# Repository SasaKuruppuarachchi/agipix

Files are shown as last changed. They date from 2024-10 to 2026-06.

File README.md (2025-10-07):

# [Agipix](https://sasakuruppuarachchi.github.io/agipix/) — Bridging Simulation and Reality for Aerial Robotics

banner

Agipix is an open hardware and software platform for agile indoor autonomy that runs the same ROS 2, containerized stack in both Isaac Sim and on the real robot. A small 438×372 mm footprint with a multi-modal sensor suite (3D LiDAR, RGB camera, IMU) and a Jetson Orin NX companion enables robust exploration and mapping with zero code changes from sim to real.

<p align="center">
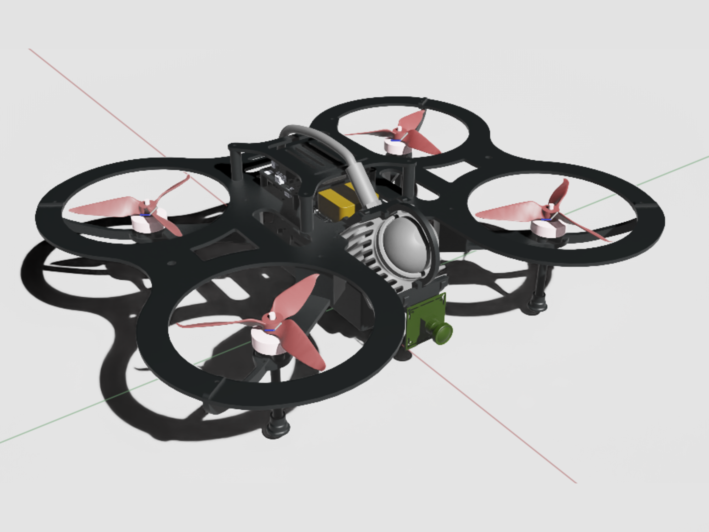
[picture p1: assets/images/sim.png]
Agipix simulation
	
	Agipix real prototype
</p>

For the accompanying paper-style write-up, see `todo` (IEEE conference format). It details hardware co-design, the LiDAR–inertial–visual stack, the Isaac Sim digital twin, and sim-to-real synchronization.

## Highlights

1) Sim-to-real deployability — Identical ROS 2 containers and configs run in Isaac Sim and on hardware; zero code changes between environments.

2) Open-source hardware and software — Full BOM, CAD, simulation assets, and the containerized ROS 2 stack are released in this repo: [bom/BOM.md](bom/BOM.md), [cad/](cad/), [model_exports/](model_exports/), [doc/](docs/), [LICENSE](LICENSE).

3) ROS 2–based modular autonomy stack — Perception, state estimation, mapping, planning, PX4 interface, and logging run as decoupled nodes/containers with DDS QoS tuning.

4) Small form factor for indoor navigation — Compact 438×372 mm envelope with guards; measured thrust-to-weight ratio (TWR) ≈ 2.98:1 for precise maneuvers in tight spaces.

5) Extensive sensor system incl. 3D LiDAR — 3D LiDAR, RGB camera, and IMU integrated into a LiDAR–inertial–visual stack for robust mapping and exploration.

6) Modular hardware with expandability — Layered decks and accessible power/data breakouts simplify sensor or compute upgrades without redesign.

## Repository layout

- `doc/` — Setup and usage guides
	- `sim/1_setup_sim.md` — Simulation setup
	- `real/1_hardware_assembly.md` — Hardware assembly
	- `real/2_flashing_hardware.Md` — Flashing and firmware
	- `real/3_software_setup.md` — Software setup on the robot
	- `autonomy/1_perception` - Perception side of the Agipix Autonomy
	- `autonomy/2_planning_control` - Planning and control side of the Agipix Autonomy
- `bom/` — Bill of Materials
	- `BOM.md` — Human-readable BOM
	- `bom.csv` — Source BOM (CSV)
- `cad/` — Mechanical CAD (designs and fabrication)
- `model_exports/` — Exported models (STL/USD) for sim and docs
- `calibration/` — Calibration assets (real and sim)
- `assets/` — Images, videos, and datasheets used in docs
- `todo` — IEEE-style paper source describing Agipix

## Quick start

### Simulation
- Follow the steps in [Simulation setup](docs/sim/1_setup_sim.md) to bring up Isaac Sim and the ROS 2 containers.

### Real hardware
- Start with [Hardware assembly](docs/real/1_hardware_assembly.md) for assembly.
- Then [Flashing and firmware](docs/real/2_flashing_hardware.Md).
- Finally [Software setup](docs/real/3_software_setup.md) to deploy the containerized stack.

## Bill of Materials (BOM)

- Browse the human-friendly BOM: [bom/BOM.md](bom/BOM.md)
- Source CSV for spreadsheets/scripts: [bom/bom.csv](bom/bom.csv)

## CAD and Simulation Assets

- Mechanical CAD and fabrication files live in `cad/`.
- Exported meshes and scene assets are in `model_exports/`.

## Paper and citation

- Main manuscript: [root.tex](root.tex) (IEEE conference format). If you use Agipix in academic work, please cite the paper once available. Until then, you may reference this repository.

## License

This project is released under the terms in [LICENSE](LICENSE).

## Acknowledgment

Agipix is supported by RAICAM, MSCA HORIZON EU.

## Contact Authors

- Sasanka Kuruppu Arachchige — sasa.kuruppuarachchi@gmail.com
- Joni Kämäräinen — joni.kamarainen@tuni.fi

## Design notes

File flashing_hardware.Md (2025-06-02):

# Compleate guide to flashing The Nvidia Jetson device to Jetpack 6.0

## Prerequisites 
1. Ubuntu 20.04 host machine x86

## Installation

4.1.2 Installing JetPack from NVIDIA® Embedded Download Center

 1. Create a new directory for installing the Jetpack. Referred to as <BSP_ROOT>
 in these instructions.

 2. Go to Jetpack Release Page https://developer.nvidia.com/embedded/jetson-linux-r363

 3. Download the "Driver Package (BSP)" and "Sample Root Filesystem" files for
 Orin modules (t234 platform).

 4. Put the "L4T Driver Package (BSP)" and "Sample Root Filesystem" in <BSP_ROOT>.
 Afterwards, you should have the following files in <BSP_ROOT>
• Jetson_Linux_R36.3.0_aarch64.tbz2
• Tegra_Linux_Sample-Root-Filesystem_R36.3.0_aarch64.tbz2

 5. Extract the "L4T Driver Package" tarball:

 cd <BSP_ROOT>
 sudo tar -jxf Jetson_Linux_R36.3.0_aarch64.tbz2

 6. You should now have a new directory called Linux_for_Tegra in your <BSP_ROOT> folder.
 Extract the "Sample Root Filesystem" into Linux_for_Tegra/rootfs.

 sudo tar -C Linux_for_Tegra/rootfs/ -xjf Tegra_Linux_Sample-RootFilesystem_R36.3.0_aarch64.tbz2

4.2 CTI BSP Installation

 1. Copy the CTI-L4T-ORIN-NX-NANO-36.3.0-V###.tgz package into
<BSP_ROOT>/Linux_for_Tegra.
If you are using Nvidia's SDK manager then "<BSP_ROOT>" will be:
 ~/nvidia/nvidia_sdk/<JetPack_Version>_Linux_JETSON_NX_ORIN_TARGETS/
 or
 ~/nvidia/nvidia_sdk/<JetPack_Version>_Linux_JETSON_NANO_ORIN_TARGETS/
 depending on your target module.

 Otherwise if manually installing from the NVIDIA® Embedded Download Center
 <BSP_ROOT> will be the folder created previously

 cp CTI-L4T-ORIN-NX-NANO-36.3.0-V###.tgz <BSP_ROOT>/Linux_for_Tegra

 2. Extract the BSP: tar -xzf CTI-L4T-ORIN-NX-NANO-36.3.0-V###.tgz
 cd <BSP_ROOT>/Linux_for_Tegra
 sudo tar -xzf CTI-L4T-ORIN-NX-NANO-36.3.0-V###.tgz

 3. Change into the CTI-L4T directory:
 cd <BSP_ROOT>/Linux_for_Tegra/CTI-L4T

 4. Run the install script (as root or sudo) to automatically install the BSP files
 to the correct locations:

 sudo ./install.sh
 #return to Linux_for_Tegra
 cd ..

 5. The CTI-L4T BSP is now installed on the host system and it should now be able
 to flash the Orin™ NX/Orin™ Nano module.

## Flasing
1. Connect an NVMe m.2 card to one of the m.2 slots on your Orin™ NX/Orin™ Nano carrier.

 2. Connect the Orin™ NX/Orin™ Nano and Carrier to the computer via USB, following the
 instructions in the appropriate manual.

 3. Put the system to be flashed into recovery mode, following the
 instructions in the appropriate manual

 4. There are two options for flashing Jetson modules:

 Using CTI's automated script:
 sudo ./cti-flash.sh

Follow the menu and select your desired configuration. Once selected,

 the device will start to flash.

 Using the Manual Method with cti-nvme-flash:

 Note do not add the ".conf" file extension to the <config> parameter:

 Manual Flash: sudo ./cti-nvme-flash.sh cti/<module>/<boardname>/<config>

 <module> is either orin-nx or orin-nano depending on your module.

 Examples:
 sudo ./cti-nvme-flash.sh cti/orin-nx/boson/base
 sudo ./cti-nvme-flash.sh cti/orin-nano/boson/base

 5. Once the flashing has completed, the Orin™ NX/Orin™ Nano will reboot 

## Connecting and first setup
1. conncet to the debug consol and follow the setup
https://jetsonhacks.com/2019/04/19/jetson-nano-serial-console/

2. skip network setup for now

3. connect to the network 
sudo nmcli dev wifi rescan

sudo nmcli d wifi connect [SSID] password [PASSWORD

4. ssh in
ssh [user]@[ip]

## Setting up Nomachine
https://kb.nomachine.com/AR02R01074

## change power mode
sudo nvpmodel -m <# of power mode>
https://forums.developer.nvidia.com/t/power-mode-in-terminal/287224

## isntalling docker and nvidia docker
https://docs.docker.com/engine/install/ubuntu/
https://docs.nvidia.com/datacenter/cloud-native/container-toolkit/latest/install-guide.html
https://git-lfs.com/

## compose and run docker

## build torchvision from source
We need to build torchvision from source in order to link against the right libraries as compiled with the NVIDIA-compiled build of pytorch
export FORCE_CUDA=1
git clone -b v0.17.2 https://github.com/pytorch/vision.git
cd vision
sudo -E python setup.py develop  # use install instead of develop if you don't care about development.

## Mount USB
https://linuxconfig.org/howto-mount-usb-drive-in-linux

## For livox lidar
- Set up the static ip of the Livox lidar Via LivoxViewer 2
- Set eth0 ip
```sudo ifconfig eth0 172.16.1.50 netmask 255.255.255.0 up```
(172.16.1.XX is the domain of the lidar)

## Referances
1. https://connecttech.com/product/hadron-carrier-for-nvidia-jetson-orin-nx/
2. https://connecttech.com/ftp/Drivers/L4T-Release-Notes/Jetson-Orin-NX-Orin-Nano/ORIN-NX-NANO-36.3.0.pdf
3. https://connecttech.com/resource-center/kdb373/
4. https://github.com/pytorch/vision/blob/main/CONTRIBUTING.md#development-installation

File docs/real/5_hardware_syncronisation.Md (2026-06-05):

---
title: Hardware Syncronisation
layout: doc
nav_title: HW Sync
---

# Hardware Syncronisation with ESP32 TimerSync Bridge

The default timesync method for Livox Lidars are PTP. But unfortunatly Jetson NX does not support PTP. The alternative in the official documentation is to use PPS syncronisation with GPS. As indoor focused robots do not have GPS, we designed the following solution to provide GPRMC and PPS signals to the Livox LiDAR and Px4 via a ESP32.

The ESP32 generates three hardware-synchronised outputs and disciplines its clock to the PX4 flight controller via MAVLink over UART.

The ESP32 firmware code can be found at [TimerSyncBridge](https://github.com/SasaKuruppuarachchi/esp32_timersync-open.git)

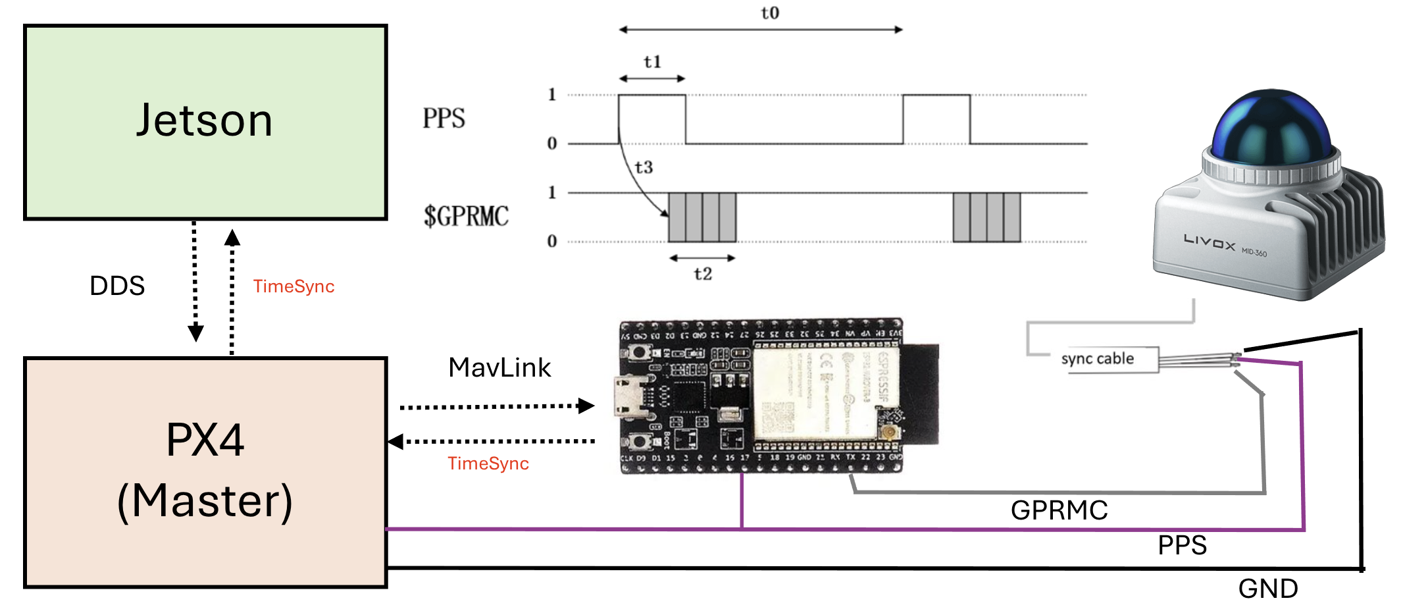
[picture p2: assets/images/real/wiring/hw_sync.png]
PPS sync wiring

---

## System Architecture

```
                          ┌─────────────────────────────────────┐
                          │   DFRobot FireBeetle 2 ESP32-S3     │
                          │                                     │
  PX4 Flight Controller   │  ┌──────────────────────────────┐   │
  (DDS time source)       │  │  Clock Discipline Layer      │   │
  GPS2  UART  ◄──────────►│  │  UNLOCKED → WARMING → LOCKED │   │
  GPIO 38/3               │  │  Source: SYSTEM_TIME MAVLink │   │
  57600 baud              │  └──────────┬───────────────────┘   │
                          │             │ UTC epoch              │
                          │  ┌──────────▼───────────────────┐   │
                          │  │  Output Generation           │   │
                          │  │  • 10 Hz PWM  GPIO 4 (LEDC)  │   │
                          │  │  • 1 Hz PPS   GPIO 5 (timer) │   │
                          │  │  • GPRMC      GPIO 12 UART1  │   │
                          │  └──┬──────────┬────────────────┘   │
                          └─────┼──────────┼──────────────────┘
                                │          │
               ┌────────────────┘          └──────────────────────────┐
               ▼                                                       ▼
  ┌────────────────────┐                          ┌────────────────────────────┐
  │  Hikrobot MVS      │                          │  Livox Mid-360             │
  │  Camera            │                          │  LiDAR                     │
  │  Line0 OPTO_IN     │                          │  Pin 8: PPS (Purple/white) │
  │  10 Hz trigger     │                          │  Pin 10: GPS/GPRMC         │
  │  → image timestamp │                          │    (Gray/white, UART 9600) │
  └────────────────────┘                          │  → UTC LiDAR stamps        │
                                                  └────────────────────────────┘
```

### Signal timing relationship

```
  1 Hz sync (GPIO 5)    ───┐           ┌───         ┌───
                           └───────────┘           └───
                           ▲ rising edge = UTC second boundary
                           │
  10 Hz trigger (GPIO 4)  ─┐─┐─┐─┐─┐  ←─ phase-reset here ─► ─┐─┐─┐─┐─┐
                            │ │ │ │ │                            │ │ │ │ │
                           100ms period, 50% duty

  GPRMC (GPIO 12 UART1)   ──[HHMMSS.00,A,...]──────────────────[HH:MM:SS+1,A,...]──
                           ▲ emitted on same rising edge
```

Every 1 Hz rising edge: LEDC timer reset (phase-aligns 10 Hz) → time increment → GPRMC emit.

---

## Hardware

| Component | Part |
|---|---|
| Timing board | DFRobot FireBeetle 2 ESP32-S3 |
| LiDAR | Livox Mid-360 |
| Camera | Hikrobot MVS (TriggerSource=LINE0) |
| Flight controller | PX4 (time sourced from companion via DDS, no GPS) |

---

## GPIO Pinout (as-built)

| Function | GPIO | Direction | Destination |
|---|---:|---|---|
| 10 Hz camera trigger | 4 | OUT | MVS camera Line0 OPTO_IN |
| 1 Hz PPS sync | 5 | OUT | Mid-360 M12 PPS interface (Pin 8, purple/white) (direct TTL) |
| GPRMC UART1 TX | 12 | OUT | Mid-360 M12 GPS input (Pin 10, Gray/white, UART 9600) |
| GPRMC UART1 RX | 13 | IN | Reserved, unused |
| MAVLink UART2 TX | 38 | OUT | PX4 GPS2 RX |
| MAVLink UART2 RX | 3 | IN | PX4 GPS2 TX |
| Status LED | 2 | OUT | On-board LED (0.5 Hz blink when LOCKED) |

---

## Px4 setup

Update Following parameters on PX4 to enable MAVLink time sync over UART2:
for refrance the project uses GPS2 port on PX4, so the parameters are:

```
MAV_1_CONFIG=GPS2
SER_GPS2_BAUD=57600
SER_GPS2_PROTO=1  # MAVLink v2
SER_GPS2_OPTIONS=0  # No flow control, no 9-bit, etc

UXRCE_DDS_SYCT=1
```

---

## Full Wiring Diagram

```
  FireBeetle 2 ESP32-S3
  ┌─────────────────────────────────────────────────────┐
  │                                                     │
  │  GPIO 4  ──────────────────────────────────────────►│  MVS Camera
  │  (10 Hz PWM 50% duty)                               │  Line0 OPTO_IN PIN 2
  │                                                     │
  │  GPIO 5  ──────────────────────────────────────────►│  Livox Mid-360
  │  (1 Hz PPS TTL 50% duty)                            │  M12 PPS interface (Pin 8, Purple/white)*
  │                                                     │  
  │  GPIO 12 (UART1 TX) ──┐────────────────────────────►│  M12 GPS input (Pin 10, Gray/white, UART 9600)*
  │  GPIO 13 (UART1 RX) ──┤                             │             
  │  (9600 baud GPRMC)    │                             │
  │                       ▼                             │
  │                  USB-Serial adapter                 │
  │                       │                             │
  │                       ▼                             │
  │                  Host /dev/ttyUSB0                  │
  │                  (to debug)                         │
  │                                                     │
  │  GPIO 38 (UART2 TX)  ──────────────────────────────►│  PX4 GPS2 RX
  │  GPIO  3 (UART2 RX)  ◄──────────────────────────────│  PX4 GPS2 TX
  │  (57600 baud MAVLink)                               │
  │  GND ───────────────────────────────────────────────│  PX4 GND
  │                                                     │
  │  USB-C (USB-CDC) ──────────────────────────────────►│  Host /dev/ttyACM0
  │  (115200 baud console)                              │  pio device monitor
  │                                                     │
  └─────────────────────────────────────────────────────┘
```
*(direct TTL for Mid-360 or when using the Livox converter 2.0, but RS485 is needed when using other LiDARs )
> **Mid-360 PPS note:** The Mid-360 accepts direct TTL on its M12 PPS interface. No TTL-to-RS485 converter is required.

> **UART TX/RX crossing:** GPIO 38 (TX) → PX4 GPS2 RX, GPIO 3 (RX) ← PX4 GPS2 TX. Cross the wires. Shared GND is mandatory.

---

## Clock Discipline Flow

```
  Power on
      │
      ▼
  UNLOCKED ──── no SYSTEM_TIME with valid epoch ────► UNLOCKED
      │
      │  SYSTEM_TIME.time_unix_usec > 1e15 µs (DDS converged)
      ▼
  WARMING ──── 3 consecutive SYSTEM_TIME samples ────► seed epoch, step-correct each
      │
      │  3 samples accumulated
      ▼
  LOCKED ──── ongoing SYSTEM_TIME updates ───────────► slew ±500 µs/update (D6)
      │                                                 GPRMC emits disciplined UTC
      │  DDS link lost
      ▼
  DEGRADED ── DDS re-converges ──────────────────────► WARMING (re-seeds)

  GPRMC output:  LOCKED → disciplined UTC sentences
                 all other states → suppressed (no output)

  1 Hz pulse and 10 Hz trigger: always running regardless of lock state
```

---

## Build and Flash

### Prerequisites
- PlatformIO CLI or VS Code PlatformIO extension
- `duracopter/MAVLink v2 C library@^2.0` (already in `platformio.ini`)

### Flash
```bash
pio run -t upload
```

### Monitor USB-CDC console
```bash
pio device monitor -b 115200
```

### Verify LiDAR time sync
The GPRMC signal goes directly to the LiDAR (M12 pin 10). Verify sync in `livox_ros_driver2` log — look for:
```
timestamp_type changed to 2
```
This confirms the LiDAR has accepted the GPRMC and switched to GPS/UART time sync mode.

---

## Expected Console Output

### Startup banner (Phase 4)
```
=== ESP32-S3 Phase 4 Timing Firmware ===
Board: DFRobot FireBeetle2 ESP32-S3
10Hz PWM trigger: GPIO 4 (LEDC low-speed timer0, 50% duty)
1Hz sync pulse:   GPIO 5 (esp_timer 500ms toggle, 50% duty)
GPRMC UART1:      TX GPIO 12, RX GPIO 13 @ 9600 baud
MAVLink UART2:    TX GPIO 38, RX GPIO 3 @ 57600 baud
DDS sync gate:    SYSTEM_TIME unix_us > 1e15 us (year >2001)
Clock discipline: UNLOCKED -> WARMING(3 samples) -> LOCKED
Max slew:         500 us/update  (D6 monotonic invariant)
GPRMC output:     disciplined UTC when LOCKED, suppressed otherwise
Invariant: on each 1Hz rising edge -> LEDC timer reset + monotonic time increment + GPRMC emit
```

### Before DDS lock (UNLOCKED/WARMING)
```
[1Hz] free=00:00:01 - GPRMC SUPPRESSED (clk=UNLOCKED), 10Hz phase reset
[MAV] HEARTBEAT sysid=1 compid=1 type=2 autopilot=12 base_mode=0x1D state=0
[MAV] SYSTEM_TIME unix_us=1780491609038000 boot_ms=2498713  dds=CONVERGED
[MAV] *** PX4 DDS timesync: CONVERGED — clock is valid ***
[CLK] state=WARMING sample=1/3  seed_unix_us=1780491609038000
[1Hz] free=00:00:02 - GPRMC SUPPRESSED (clk=WARMING), 10Hz phase reset
[CLK] state=WARMING sample=2/3  offset=1711 us
[CLK] state=WARMING sample=3/3  offset=-15801 us
[CLK] *** state=LOCKED — disciplined clock valid ***
```

### After LOCKED
```
[1Hz] disc=13:00:15 free=00:00:08 - GPRMC emitted (LOCKED), 10Hz phase reset
[CLK] state=LOCKED  disc_utc=13:00:16  offset=-1178 us  corr=-500 us  total_corr=-500 us  drift_trend=14623 us
[HB] uptime=10s  free=00:00:10  disc_utc=13:00:17  clk=LOCKED  px4_dds=CONVERGED
[MAV] TIMESYNC RTT=20639 us
```

### GPRMC output (GPIO 12 → Mid-360 pin 10, 9600 baud, after LOCKED)
```
$GPRMC,130015.00,A,2237.496474,N,11356.089515,E,0.0,225.5,230520,2.3,W,A*2E
$GPRMC,130016.00,A,2237.496474,N,11356.089515,E,0.0,225.5,230520,2.3,W,A*2D
$GPRMC,130017.00,A,2237.496474,N,11356.089515,E,0.0,225.5,230520,2.3,W,A*2C
```
Time field reflects real UTC from PX4. Checksum is valid NMEA XOR. Status field is `A` (active).

---

## livox_ros_driver2 Configuration

Time sync is configured in the Livox SDK JSON config used by `livox_ros_driver2`. The ESP32 acts as a GPS emulator — it provides both the 1 Hz PPS hardware edge (Mid-360 pin 8) and the GPRMC sentence (Mid-360 pin 10) directly. No host serial adapter is needed.

Reference: [Livox time sync via UART](https://livox-wiki-en.readthedocs.io/en/latest/tutorials/new_product/common/time_sync.html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)

The driver validates: `$GPRMC`/`$GNRMC` prefix, status field `A`, and checksum. It does **not** validate position or that the UTC value is current.

### Verification
After launching `livox_ros_driver2`, look for this log entry:
```
timestamp_type changed to 2
```
`timestamp_type 2` = GPS/UART sync active. If it reads `0` or `1`, the GPRMC signal is not reaching the LiDAR — check the GPIO 12 → pin 10 wire and GND continuity.

---

## Project Status

| Phase | Description | Status |
|---|---|---|
| 1 | ESP32 board bring-up — LEDC 10 Hz, 1 Hz PPS, free-running GPRMC | ✅ COMPLETE |
| 2 | MAVLink link bring-up — HEARTBEAT, SYSTEM_TIME, TIMESYNC via UART2 | ✅ COMPLETE |
| 3 | Clock discipline — DDS-gated UNLOCKED→WARMING→LOCKED state machine | ✅ COMPLETE |
| 4 | Disciplined GPRMC — UTC time from PX4 drives GPRMC output | ✅ COMPLETE — 32 min soak verified (offset ±13 ms, zero DEGRADED, ~16 µs/min drift) |
| 5 | Full integration — Mid-360 + MVS camera end-to-end | ✅ COMPLETE — PPS sync active, `timestamp_type changed to 2` confirmed |

---

## Phase 4 Soak Results (32-minute pre-Phase-5 run)

Continuous run with PX4 DDS active, no sensor hardware connected yet.

| Metric | Observed | Pass threshold |
|---|---|---|
| Clock state | LOCKED throughout | no DEGRADED transitions |
| Uptime | 1931 s (32 min) | — |
| GPRMC gaps | 0 | 0 |
| LOCKED offset range | ±13 ms | < ±50 ms (UART jitter) |
| Accumulated drift correction | −31 ms over 32 min (~16 µs/min) | stable tracking |
| MAVLink RTT | 20.6 ms (stable) | < 100 ms |
| px4_dds status | CONVERGED throughout | CONVERGED |

Representative log extract (uptime 1931 s):
```text
[HB] uptime=1931s  free=00:32:12  disc_utc=13:32:19  clk=LOCKED  px4_dds=CONVERGED
[CLK] state=LOCKED  disc_utc=13:32:20  offset=-12605 us  corr=-500 us  total_corr=-32166 us
[MAV] TIMESYNC RTT=20636 us
```

**Result: PASS.** Clock discipline is stable over the soak window. Proceeding to Phase 5.

## Phase 5 Integration Checklist

Connect the Mid-360 LiDAR and MVS camera to the ESP32 and run the full sensor stack.

**Step 1 — Wiring**
- GPIO 5 → Mid-360 M12 pin 8 (PPS, Purple/white, direct TTL 3.3V, no RS485)
- GPIO 12 UART1 TX → Mid-360 M12 pin 10 (GPS input, Gray/white, direct TTL 3.3V)
- GPIO 4 → MVS camera Line0 OPTO_IN
- Shared GND between ESP32 and Mid-360 M12 connector

**Step 2 — Host config**
- No serial adapter needed — GPRMC goes directly to LiDAR hardware
- Set camera: `TriggerMode=1`, `TriggerSource=LINE0`, `ExposureTime=5000`

**Step 3 — Launch**
- Flash ESP32 (`pio run -t upload`)
- Wait for `[CLK] *** state=LOCKED` in console before starting ROS nodes
- Launch `livox_ros_driver` and MVS camera driver

**Verification gate:**
- [ ] `livox_ros_driver2` log shows `timestamp_type changed to 2` on startup
- [ ] LiDAR point cloud timestamps are UTC-anchored (`sec` matches current UTC, not boot-relative)
- [ ] MVS camera triggers at 10 Hz confirmed in ROS topic
- [ ] 30-minute continuous run — no DEGRADED transitions in ESP32 console log
- [ ] Rosbag captured for evidence

---

## Troubleshooting

| Symptom | Likely cause | Fix |
|---|---|---|
| No `[MAV] HEARTBEAT` | UART2 wiring wrong or baud mismatch | Check GPIO 38→PX4 RX, GPIO 3←PX4 TX, shared GND; verify `SER_TELx_BAUD=57600` on PX4 |
| `clk=WARMING` never advances | PX4 DDS not converged | Check `uxrce_dds_client status` on PX4 NSH — need `timesync converged: true` |
| GPRMC suppressed indefinitely | Clock never reaches LOCKED | Usually DDS convergence issue; see above |
| `livox_ros_driver2` does not show `timestamp_type changed to 2` | GPRMC not reaching LiDAR | Check GPIO 12 → Mid-360 pin 10 wire and shared GND; confirm ESP32 is LOCKED before starting driver |
| 10 Hz or 1 Hz signal absent | GPIO conflict or wiring | Confirm scope on GPIO 4 and GPIO 5; check no strapping pin conflict |
| Large offset at LOCKED entry | Normal — WARMING step-corrects | Offset drops to <20 ms within a few SYSTEM_TIME updates after LOCKED |

---

## Repository Layout

```
esp32_timersync-open/
├── src/
│   └── main.cpp              # All firmware — Phase 1–4 complete
├── include/                  # Headers (currently empty)
├── platformio.ini            # Board: dfrobot_firebeetle2_esp32s3, lib: MAVLink v2
└── .copilot_instrcutions/    # Project knowledge base
    ├── SYSTEM_KNOWLEDGE.md   # Hardware facts, signal specs, verified GPIO table
    ├── PLAN.md               # Phase-gated implementation plan
    └── DECISIONS.md          # Resolved decisions and open questions
```

## Documentaion Reference

* [Wiki](https://github.com/Livox-SDK/Livox-SDK/wiki/livox-device-time-synchronization-manual)
* [PX4](https://discuss.px4.io/t/how-to-test-the-time-synchronization-between-radar-and-camera)
* [Livox ROS Driver](https://github.com/Livox-SDK/livox_ros_driver2)
* [LIV_handhold](https://github.com/xuankuzcr/LIV_handhold)

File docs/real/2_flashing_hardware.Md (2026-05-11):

---
title: Flashing Jetson & Carrier
layout: doc
nav_title: Flashing Hardware
---

# Flashing the NVIDIA Jetson (JetPack 6.x)

Refer to the [Datasheets](../../assets/datasheets/CTIM-00088.pdf) and install the Jetson Orin NX module, wiring and power to the Hadron carrier. 
Refer the [Official Page](https://connecttech.com/product/hadron-carrier-for-nvidia-jetson-orin-nx/) For the download of the latest official BSP (Board Support Package) and release notes which contains the firmware install instructions.

> Note: These steps target Jetson Orin NX/Nano on Connect Tech carriers (Hadron, etc.), Jetson Linux R36.3. Adjust versions as needed. 
**Tested for CT Hadron NGX027 with the Jetpack 6.2.1 - L4T r36.4.4 (BSP Version: ORIN-NX-NANO-36.4.4 V002)**

Prerequisities:
- x86/x64 based host machine running Ubuntu 20.04 or 22.04
- JetPack 6.2.1 / L4T 36.4.4 installed (Intstructions follows)
- Orin™ NX or Orin™ NX module
- Connect Tech Orin™ NX/Orin™ NX Carrier
- USB A - USB A Cable for flashing

## Install Wifi and SSD

Install the [wifi](https://www.intel.com/content/www/us/en/products/sku/230078/intel-wifi-7-be200/specifications.html) and [ssd](https://www.verkkokauppa.com/fi/product/906691/WD-Black-SN770M-1-Tt-M-2-NVMe-SSD-kovalevy) cards to the PCI mini E and M slots respectively.

## Powering up the carrier
The 6S Lipo can be used to power up the board directly. Install a 60V capacitor between the terminals of the main power.
Alternatively a AC DC adapter with min 40 W (10-60V) can be used.
 Get the board ready to be powered up for he flashing of firmware.

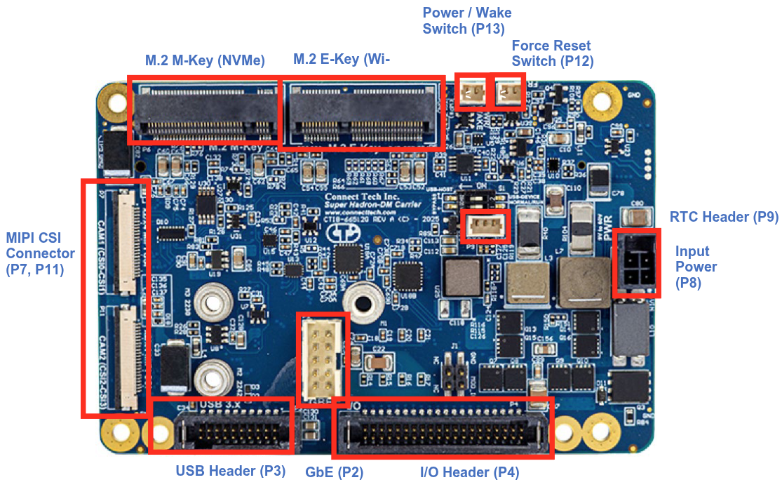
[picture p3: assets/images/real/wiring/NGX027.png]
Hadron Carrier


## What you’ll do
- Prepare a host machine and download JetPack BSP + sample rootfs
- Install the CTI BSP on the host
- Put the Jetson in recovery mode and flash (auto or manual)
- Perform first boot steps and basic post-setup

---

## 1) Get JetPack (Driver Package + RootFS)

1) Create a working directory, referred to as BSP_ROOT below.

2) Open the Jetson Linux R36.4.4 downloads and notes:
   - Driver page: https://developer.nvidia.com/embedded/jetson-linux-r3644

3) Download both for Orin (LT4):
   - Driver Package (BSP): Jetson_Linux_R36.4.4_aarch64.tbz2
   - Sample Root Filesystem: Tegra_Linux_Sample-Root-Filesystem_R36.4.4_aarch64.tbz2

4) Place both files under BSP_ROOT, then extract them:

```bash
cd <BSP_ROOT>
sudo tar -jxf Jetson_Linux_R36.4.4_aarch64.tbz2
sudo tar -C Linux_for_Tegra/rootfs/ -xjf Tegra_Linux_Sample-Root-Filesystem_R36.4.4_aarch64.tbz2
```

After extraction, you should have `<BSP_ROOT>/Linux_for_Tegra` populated.

---

## 2) Install the CTI BSP

If you used NVIDIA SDK Manager, BSP_ROOT is typically:
- `~/nvidia/nvidia_sdk/<JetPack_Version>_Linux_JETSON_NX_ORIN_TARGETS/`
- or `~/nvidia/nvidia_sdk/<JetPack_Version>_Linux_JETSON_NANO_ORIN_TARGETS/`

If you manually downloaded from the Embedded Download Center, use the folder you created as BSP_ROOT.

Download the CTI BSP from [CTI BSP Downloads](https://connecttech.com/product/super-hadron-dm-carrier-for-nvidia-jetson-orin-nx/).

For the firmware with real time kernel RT_PREEMPT download the `JetPack 6.2.1 – L4T r36.4.4 (RealTime OS)` package instead of the base package.

1) Copy the CTI package to Linux_for_Tegra:

```bash
cp CTI-L4T-ORIN-NX-NANO-RT-36.4.4-V005.tgz BSP_ROOT/Linux_for_Tegra
```

2) Extract it and run the installer:

```bash
cd <BSP_ROOT>/Linux_for_Tegra
sudo tar -xzf CTI-L4T-ORIN-NX-NANO-RT-36.4.4-V005.tgz
cd CTI-L4T
sudo ./install.sh
cd .. # back to Linux_for_Tegra
```

> The CTI-L4T BSP is now installed on the host, and you can flash Orin NX/Nano.

---

## 3) Put the device in Recovery Mode

1) Connect the carrier to your host via USB per the carrier manual.
2) Ensure an NVMe M.2 SSD is installed.
3) Follow the carrier instructions to enter recovery (button/strap sequence). 
> For NGX027 to put the Jetson module into Force Recovery mode, install a jumper and then power on the platform. After 10 seconds remove the jumper shunt and the device will now be in Force Recovery mode.

Tip: You can verify via `lsusb` for an NVIDIA device in recovery.
```shell
Bus 001 Device 024: ID 0955:7323 NVIDIA Corp. APX
```

---

## 4) Flashing options

You can use either the CTI automated script or the manual NVMe flash script.

### Option A: Automated (menu-driven)

```bash
cd <BSP_ROOT>/Linux_for_Tegra
sudo ./cti-flash.sh
```
Follow the menu to select your module and board configuration. Flashing will begin.

> `Vision Components IMX296` [camera option](https://www.mouser.fi/ProductDetail/Vision-Components/MIPI-IMX296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) for Orin NX is recommended for direct connection to the board.
[This](https://connecttech.com/supported-cameras/) Lists all the commpatible cameras.
[This](https://wdl.ai/connect-tech-allied-vision-mipi-csi-2) shows how to connect Allied vision cameras using adapter.

### Option B: Manual NVMe flash

Do not include the `.conf` extension in `<config>`.

```bash
cd <BSP_ROOT>/Linux_for_Tegra
sudo ./cti-nvme-flash.sh cti/<module>/<boardname>/<config>
# <module> is one of: orin-nx | orin-nano
```
Examples:
```bash
./cti-nvme-flash.sh cti/orin-nx/boson/base
./cti-nvme-flash.sh cti/orin-nano/boson/base
SUPER_MODE=1 ./cti-nvme-flash.sh cti/orin-nx/hadron/base
```

When flashing completes, the device will reboot.
```bash
Flash is successful
Reboot device
Cleaning up...
Log is saved to
```
---

### 5.1) Troubleshoot Flashing
#### ISSUE1 : A USB timeout error may occur during flashing. The following error indicates that your flash host’s USB port is not enabled:

```bash
[ 0.1172 ] Sending bct_br
[ 0.1603 ] ERROR: might be timeout in USB write.
Error: Return value
```
##### 1. First try changing the USB port:

- Move to a different USB port, if available.

- **Remove any USB-C docks if connected**

- Power cycle the board and retry flashing.

##### 2. If that doesn’t work, try disabling autosuspend:

To disable autosuspend on your host’s USB ports, run the following command.
```bash
sudo bash -c 'echo -1 > /sys/module/usbcore/parameters/autosuspend'
```
Power cycle the board and retry flashing.

#### ISSUE2 : Cnnot mount the NFS server

```bash
12:52:45.297 - Error: Flash failure. 
12:52:45.300 - Error: Either the device cannot mount the NFS server on the host or a flash command has failed. Check your network setting (VPN, firewall,...) to make sure the device can mount NFS server. Debug log saved to /tmp/tmp.2HZma7rFSi. You can access the target's terminal through "sshpass -p root ssh root@fc00:1:1:0::2"
```

##### 1. Disable VPN completely

CTI initrd flashing fails 100% if a VPN is on.

##### 2. Restart NFS and RPC services
```bash
sudo systemctl stop rpcbind rpcbind.socket nfs-kernel-server
sudo systemctl start rpcbind rpcbind.socket nfs-kernel-server
```

Check status:

```bash
systemctl status nfs-kernel-server
```
##### 3. Ensure firewall isn't blocking NFS (especially IPv6)

Temporarily disable ufw (if running):

```bash
sudo ufw disable
```
## 5) First boot and basic setup

### Connect via serial console (recommended)
- Connect to the **Serial debug port** of the Carrier using a TTL to USB adapter. (ex: FTDI)
- Guide: https://jetsonhacks.com/2019/04/19/jetson-nano-serial-console/ 
```bash
sudo minicom -D /dev/ttyUSB0 -b 115200
```
- Complete the initial setup prompts. You can skip network here and do it below.
```bash
System Configuration
           ┌────┤ License For Customer Use of NVIDIA Software ├─────┐
           │                                                        │
           │ Welcome to Jetson Initial Configuration                │
           │                                                        │
           │                         <Ok>                           │
           │                                                        │
           └────────────────────────────────────────────────────────┘
```

### Join Wi‑Fi via nmcli
```bash
sudo nmcli dev wifi rescan
sudo nmcli dev wifi connect <SSID> password <PASSWORD>
```

### SSH in
```bash
ssh <user>@<device-ip>
```

---

## 6) Useful post-setup

### Setup Git
```bash
git config --global user.name "John Doe"
git config --global user.email johndoe@example.com
```

### Increase Swap 
You may need to increase swap depending on he RAM of your Jetson module
Follow [This Guide](https://www.forecr.io/blogs/programming/how-to-increase-swap-space-on-jetson-modules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) to upgrade swap memeory.

```bash
free -h # Check current memory usage
df -h # Check current disk usage

# start from here to increase swap size to 16G
sudo fallocate -l 16G /swapfile # Allocate 16G of space for swap file
ls -lh /swapfile # Verify the swap file is created
sudo chmod 600 /swapfile # Set the correct permissions for the swap file
sudo mkswap /swapfile 
sudo swapon /swapfile
free -h # Check current memory usage   

# to make the change persistent across reboots, add the swap file to /etc/fstab:
sudo cp /etc/fstab /etc/fstab.bak
echo '/swapfile none swap sw 0 0' | sudo tee -a /etc/fstab
```

### Install Jetpack extras and Jtop
```bash
sudo apt install nvidia-jetpack

# Setup jtop
sudo apt update && sudo apt upgrade -y
sudo apt install python3-pip -y && sudo apt install curl -y
sudo pip3 install -U jetson-stats
mkdir hacks && cd hacks
git clone https://github.com/jetsonhacks/jetson-jtop-patch.git
cd jetson-jtop-patch
chmod +x apply_jtop_fix.sh
./apply_jtop_fix.sh
```
Once pip installs the jetson-stats package, you will need to logout/login or reboot the Jetson.

After rebooting, to run jtop open a Terminal and execute: `jtop`

### NoMachine (remote desktop)
To setup remote desktop to the headless system for debugging follow [this guide](https://kb.nomachine.com/AR02R01074)

```bash
wget https://web9001.nomachine.com/download/9.4/Arm/nomachine_9.4.14_1_arm64.deb
sudo dpkg -i nomachine_9.4.14_1_arm64.deb 
sudo systemctl disable gdm3 --now
sudo /usr/NX/bin/nxserver --restart
```

### Change power mode
```bash
sudo nvpmodel -m <mode-number>
```
- Reference: https://forums.developer.nvidia.com/t/power-mode-in-terminal/287224

### Install VSCode
```bash
cd hacks
git clone https://github.com/JetsonHacksNano/installVSCode.git
cd installVSCode
./installVSCodeWithPython.sh
```

### Cuda and cudnn
If cuda packages are not installed. ```ls /usr/local | grep cuda``` returns nothing
```bash
sudo apt install cuda-toolkit-12-6
```

if cudnn not installed. ```dpkg -l | grep cudnn``` returns nothing, [Get Cudnn](https://developer.nvidia.com/cudnn-downloads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)
```bash
wget https://developer.download.nvidia.com/compute/cudnn/9.16.0/local_installers/cudnn-local-tegra-repo-ubuntu2204-9.16.0_1.0-1_arm64.deb
sudo dpkg -i cudnn-local-tegra-repo-ubuntu2204-9.16.0_1.0-1_arm64.deb
sudo cp /var/cudnn-local-tegra-repo-ubuntu2204-9.16.0/cudnn-*-keyring.gpg /usr/share/keyrings/
sudo apt-get update
sudo apt-get -y install cudnn9-cuda-12
```

### Setup ```.bashrc```

Add following lines to your ```.bashrc``` to link important cuda libraries
```bash
export CUDA=12.6
export PATH=/usr/local/cuda-$CUDA/bin${PATH:+:${PATH}}
export CUDA_PATH=/usr/local/cuda-$CUDA
export CUDA_HOME=/usr/local/cuda-$CUDA
export LIBRARY_PATH=$CUDA_HOME/lib64:$LIBRARY_PATH
export LD_LIBRARY_PATH=/usr/local/cuda-$CUDA/lib64${LD_LIBRARY_PATH:+:${LD_LIBRARY_PATH}}
export LD_LIBRARY_PATH=/usr/local/cuda/extras/CUPTI/lib64:$LD_LIBRARY_PATH
export NVCC=/usr/local/cuda-$CUDA/bin/nvcc
export CFLAGS="-I$CUDA_HOME/include $CFLAGS"
export LD_LIBRARY_PATH=/usr/local/cuda-$CUDA/targets/aarch64-linux/lib:$LD_LIBRARY_PATH
export CPATH=/usr/local/cuda-$CUDA/targets/aarch64-linux/include:$CPATH
```
Source your ```.bshrc```

#### Verify Cuda and CUDNN
```bash
echo '#include <cuda_runtime.h>
#include <cudnn.h>
#include <iostream>
int main() {
    int cudaVersion;
    cudaRuntimeGetVersion(&cudaVersion);
    std::cout << "CUDA runtime version: " << cudaVersion/1000 << "." << (cudaVersion%1000)/10 << std::endl;
    std::cout << "cuDNN version: " << CUDNN_MAJOR << "." << CUDNN_MINOR << "." << CUDNN_PATCHLEVEL << std::endl;
    return 0;
}' > verify_cuda_cudnn.cpp && \
g++ verify_cuda_cudnn.cpp \
    -I/usr/local/cuda-12.6/targets/aarch64-linux/include \
    -L/usr/local/cuda-12.6/targets/aarch64-linux/lib \
    -lcudart -lcudnn -o verify_cuda_cudnn && \
./verify_cuda_cudnn
```

### Fix Snap apps
If Snap apps like Chromium is not working, [ref](https://jetsonhacks.com/2025/07/12/why-chromium-suddenly-broke-on-jetson-orin-and-how-to-bring-it-back/)
```bash
snap download snapd --revision=24724
sudo snap ack snapd_24724.assert
sudo snap install snapd_24724.snap
sudo snap refresh --hold snapd
```

### Mount a USB drive
- https://linuxconfig.org/howto-mount-usb-drive-in-linux

### Wezterm and Superfile
Install wezterm
```bash
curl -fsSL https://apt.fury.io/wez/gpg.key | sudo gpg --yes --dearmor -o /usr/share/keyrings/wezterm-fury.gpg
echo 'deb [signed-by=/usr/share/keyrings/wezterm-fury.gpg] https://apt.fury.io/wez/ * *' | sudo tee /etc/apt/sources.list.d/wezterm.list
sudo chmod 644 /usr/share/keyrings/wezterm-fury.gpg

sudo apt update

sudo apt install wezterm

sudo update-alternatives --config x-terminal-emulator # set to wezterm
```
Install Superfile
```bash
bash -c "$(curl -sLo- https://superfile.dev/install.sh)"
```

---

## References
1) Hadron carrier: https://connecttech.com/product/hadron-carrier-for-nvidia-jetson-orin-nx/
2) CTI L4T release notes (36.3.0): https://connecttech.com/ftp/Drivers/L4T-Release-Notes/Jetson-Orin-NX-Orin-Nano/ORIN-NX-NANO-36.3.0.pdf
3) CTI knowledge base: https://connecttech.com/resource-center/kdb373/
4) torchvision dev install: https://github.com/pytorch/vision/blob/main/CONTRIBUTING.md#development-installation

---

### Continue
- ← Back: [Hardware Assembly](./1_hardware_assembly.md)
- Next → [Software Setup](./3_software_setup.md)

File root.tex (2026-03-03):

%2345678901234567890123456789012345678901234567890123456789012345678901234567890
%        1         2         3         4         5         6         7         8

\documentclass[letterpaper, 10 pt, conference]{ieeeconf}  % Comment this line out if you need a4paper

%\documentclass[a4paper, 10pt, conference]{ieeeconf}      % Use this line for a4 paper

\IEEEoverridecommandlockouts                              % This command is only needed if 
                                                          % you want to use the \thanks command

\overrideIEEEmargins                                      % Needed to meet printer requirements.

\usepackage{cite}
\usepackage{amsmath,amssymb,amsfonts}
\usepackage{algorithmic}
\usepackage{etoolbox}
\usepackage{graphicx}
\usepackage{subcaption}
\usepackage{textcomp}
\def\BibTeX{{\rm B\kern-.05em{\sc i\kern-.025em b}\kern-.08em
    T\kern-.1667em\lower.7ex\hbox{E}\kern-.125emX}}
\usepackage{dsfont}
\usepackage{paralist}
\usepackage{capt-of}
\usepackage{tabularx}
\usepackage{cancel}
\usepackage{bm}
\usepackage{url}
\usepackage{mathtools}
\usepackage{nccmath}
\usepackage{xcolor}
\usepackage{multirow}
\usepackage{hhline}
\usepackage{booktabs}
\usepackage{siunitx}
\usepackage{pifont}
\usepackage{comment}
% Paper-local helpers
\newcommand{\Agipix}{AgiPIX}
\newcommand{\Agiautonomy}{AgiAUTO}
\newcommand{\Agisim}{AgiSIM}
\newcommand{\Agiui}{AgiUI}
\newcommand{\Agihw}{AgiREAL}
\newcommand{\Agipixs}{AgiPIX }
\newcommand{\Agiautonomys}{AgiAUTO }
\newcommand{\Agisims}{AgiSIM }
\newcommand{\Agiuis}{AgiUI }
\newcommand{\Agihws}{AgiREAL }
\newcommand{\TODO}[1]{\textcolor{red}{#1}}
\newcommand{\CHANGDA}[1]{\textcolor{green}{#1}}
\newcommand{\cmark}{\ding{51}}
\newcommand{\xmark}{\ding{55}}

\title{\LARGE \bf
\Agipix: Bridging Simulation and Reality in Indoor Aerial Inspection
}

\author{Undisclosed Authors}
% \author{Sasanka Kuruppu Arachchige$^{1}$, Juan Jose Garcia$^{2}$, Changda Tian$^{3}$, Lauri Suomela$^{1}$, \\ Panos Trahanias$^{3}$ , Adriana Tapus$^{2}$ and Joni Kämäräinen$^{1}$% <-this % stops a space
% \thanks{*This work was supported by RAICAM, MSCA HORIZON EU}% <-this % stops a space
% \thanks{$^{1}$Sasanka Kuruppu Arachchige, Lauri Suomela and Joni Kämäräinen are with the Computing Sciences department at Tampere University, Finland
%         {\tt\small sasa.kuruppuarachchi@gmail.com, joni.kamarainen@tuni.fi}}%
% \thanks{$^{2}$Juan Jose Garcia and Adriana Tapus are with U2IS at ENSTA, Paris
%         {\tt\small juan-jose.garcia@ensta.fr, adriana.tapus@ensta.fr}}%
% \thanks{$^{3}$Changda Tian and Panos Trahanias is with Institute of Computer Science, Foundation for Research and Technology - Hellas (FORTH), Heraklion, Greece.
%         {\tt\small dada@ics.forth.gr, trahania@ics.forth.gr}}%
% }

\begin{document}
% Reduce layout warnings from tight two-column formatting.
\raggedbottom
\setlength{\emergencystretch}{2em}
\sloppy
\hbadness=10000
\vbadness=10000

% Graphics path for figures used across the paper
\graphicspath{{images/}}

\newcommand{\insertfig}{\captionof{figure}{\Agipix{} is an open platform for indoor aerial autonomy and critical asset inspection. Left: Mapping result and a PoV view of a simulated drone (\Agisim). Center: \Agipixs \Agihw::UAV hardware prototype used in field experiments. Right: Mapping result and a PoV view of a real \Agihw::UAV surveying the AKW Zwentendorf nuclear power plant, Austria.}}\label{fig:coverfig}%

\makeatletter
\apptocmd{\@maketitle}{\centering\insertfig}{}{}% insert the figure after authors
\makeatother
%*************************************

\maketitle
\setcounter{figure}{1}
\thispagestyle{empty}
\pagestyle{empty}

%%%%%%%%%%%%%%%%%%%%%%%%%%%%%%%%%%%%%%%%%%%%%%%%%%%%%%%%%%%%%%%%%%%%%%%%%%%%%%%%
\begin{abstract}
Autonomous indoor flight for critical asset inspection presents fundamental challenges in perception, planning, control, and learning. Despite rapid progress, there is still a lack of a compact, active-sensing, open-source platform that is reproducible across simulation and real-world operation. To address this gap, we present \Agipix, a co-designed open hardware and software platform for indoor aerial autonomy and critical asset inspection. \Agipixs features a compact, hardware-synchronized active-sensing platform with onboard GPU-accelerated compute that is capable of agile flight; a containerized ROS~2-based modular autonomy stack; and a photorealistic digital twin of the hardware platform together with a reliable UI. These elements enable rapid iteration via zero-shot transfer of containerized autonomy components between simulation and real flights. We demonstrate trajectory tracking and exploration performance using onboard sensing in industrial indoor environments. All hardware designs, simulation assets, and containerized software are released openly together with documentation.\\
\end{abstract}
\urlstyle{same}
{\bfseries\textit{Multimedia Material}}--- \\ 
For complete documentation, code, and assets, \\ \url{https://sasakuruppuarachchi.github.io/agipix/} \relax

%%%%%%%%%%%%%%%%%%%%%%%%%%%%%%%%%%%%%%%%%%%%%%%%%%%%%%%%%%%%%%%%%%%%%%%%%%%%%%%%
\section{INTRODUCTION}\label{sec:introduction}

Critical asset inspection is a key application domain for autonomous aerial robots, with growing demand across industrial facilities, energy plants, warehouses, tunnels, and other confined indoor environments. Traditional inspection is labor-intensive, costly, time-consuming, and can expose operators to safety risks in hard-to-reach or hazardous areas \cite{sanchez2024toward}. Recent advances in aerial robotics improve inspection efficiency, coverage, and safety through remote, automated data collection with onboard sensing. Commercial systems perform well outdoors, but indoor aerial inspection remains more challenging due to limited space, lack of global positioning, poor lighting, and the need for reliable close-proximity operation around obstacles and assets.

To advance the field, several research sprints have been organized, including the DARPA Subterranean Challenge \cite{tranzatto2022cerberus} for autonomous exploration in complex indoor environments and the European Robotics Hackathon (ENRICH) \cite{europeanroboticsENRICH2025} for critical asset inspection. These events enable real-world testing inside a decommissioned nuclear power plant under authentic radiological conditions. As a result, only a few research groups \cite{tranzatto2022cerberus, Foehn2022Agilicious, microswarm2022fast} have gained the expertise and resources needed to develop aerial robotic platforms, given the significant hardware and software engineering overhead.

This work aims to bridge this gap by providing an open, compact, actively sensed aerial robotics platform for indoor inspection and mapping, with a focus on reproducibility and sim-to-real transfer.

The main contributions of this paper are:
\begin{itemize}
        \item \textbf{\Agihw: Open source hardware for indoor inspection:} We present a compact, high-performance aerial platform with hardware-synchronized 3D LiDAR for precise mapping and robust navigation.
        \item \textbf{\Agiautonomy: Open source modular software:} We implement a ROS~2-based modular autonomy stack in a dockerized environment for rapid deployment.
        \item \textbf{\Agisim: Digital twin:} We provide a photorealistic Isaac Sim based digital twin~\cite{nvidiaIsaacSim2026}.
        \item \textbf{\Agiui: User interface:} We implement a low-bandwidth operator interface for mission control.
        \item \textbf{Experiments:} We report results from simulation and real-world experiments.
\end{itemize}

The paper is organized as follows: Section~\ref{sec:related} reviews related work; Section~\ref{sec:platform} presents the \Agipixs platform; Section~\ref{sec:results} reports results; Section~\ref{sec:discussion} discusses limitations and future directions; and Section~\ref{sec:conclusion} concludes.

\section{RELATED WORK} \label{sec:related}
Related work covers open aerial platforms, perception, planning, and control, simulation and digital twins, and UI.

\begin{figure*}[!ht]
    \centering
    % 	\centering
    \vspace*{-12pt}
    
    \vspace*{-10pt}
    
    \def\arraystretch{1.1}
	\resizebox{\textwidth}{!}{%
        \begin{tabular}{@{}l|c|c|c|c|c|r|c|c|c|r|r}
        	\toprule
        	framework & open-source & ROS~2 & simulation & \parbox{1.5cm}{\centering user interface} & \parbox{2.0cm}{\centering low-level controller} & \parbox{1.8cm}{\centering CPU Mark \\ (higher is better)} & GPU & \parbox{1.15cm}{\centering 3D LiDAR} & \parbox{1.6cm}{\centering Collision guard} & \parbox{1.3cm}{\centering thrust / weight} & \parbox{1.6cm}{\centering Diagonal span (mm)}\\
        	\midrule
        	DJI M400~\cite{djiMatrice400Specs2026} & - & \textcolor{green}{\cmark} & \textcolor{red}{\xmark} & \textcolor{green}{\cmark}  & proprietary & - & \textcolor{green}{\cmark} & \textcolor{green}{\cmark} & \textcolor{red}{\xmark} &  - & $\approx1240$\\
        	%
        	Skydio X10~\cite{skydioX102026} & - & \textcolor{red}{\xmark}  & \textcolor{red}{\xmark} & \textcolor{green}{\cmark}  & proprietary &  - & \textcolor{green}{\cmark} & \textcolor{red}{\xmark} & \textcolor{red}{\xmark} & -  & $\approx1023$\\
            %
            Flyability~\cite{flyabilityElios32022} & - & \textcolor{red}{\xmark} & \textcolor{green}{\cmark} & \textcolor{green}{\cmark} & proprietary & - & \textcolor{green}{\cmark} & \textcolor{green}{\cmark}& \textcolor{green}{\cmark}& - & $\approx480$ \\
        	%
        	Crazyflie~\cite{GiernackiCrazy} & SW and HW & \textcolor{green}{\cmark} & \textcolor{green}{\cmark} & \textcolor{red}{\xmark} & custom & - & \textcolor{red}{\xmark} & \textcolor{red}{\xmark} & \textcolor{red}{\xmark} & $\approx2.26$  & $\approx92$\\
        	%
        	FLA-Quad~\cite{Mohta18jfr} & SW and HW & \textcolor{red}{\xmark} & \textcolor{green}{\cmark} & \textcolor{red}{\xmark} & PX4 & $3{,}383$ & \textcolor{red}{\xmark} & \textcolor{green}{\cmark} & \textcolor{red}{\xmark} & $\approx2.38$ & -   \\
        	Borinot~\cite{marti2023borinot} & SW and HW & \textcolor{green}{\cmark} & \textcolor{green}{\cmark} & \textcolor{red}{\xmark} & PX4 & $6{,}190$ & \textcolor{red}{\xmark} & \textcolor{red}{\xmark} & \textcolor{red}{\xmark} & $\approx3.50$  &  $\approx516$ \\
        	%
        	MRS UAV~\cite{Baca2021jirs} & SW and HW & \textcolor{green}{\cmark} & \textcolor{green}{\cmark} & \textcolor{green}{\cmark} & PX4 & $9{,}264$ & \textcolor{red}{\xmark} & \textcolor{green}{\cmark} & \textcolor{red}{\xmark} & $\approx2.50$ & $\approx792$  \\
        	%
        	Agilicious~\cite{Foehn2022Agilicious} & SW and HW* & \textcolor{red}{\xmark} & \textcolor{green}{\cmark}\textcolor{green}{\cmark} & \textcolor{green}{\cmark} & custom & $1{,}343$ & \textcolor{green}{\cmark} & \textcolor{red}{\xmark} & \textcolor{red}{\xmark} & $\approx5.00$ & $\approx382$  \\
            %
            OmniNxt~\cite{liu2024omninxt} & SW and HW & \textcolor{green}{\cmark} & \textcolor{red}{\xmark} & \textcolor{green}{\cmark} & PX4 & $2{,}418$ & \textcolor{green}{\cmark} & \textcolor{red}{\xmark} & \textcolor{green}{\cmark} & $\approx4.24$  & $\approx250$  \\

                \midrule
        	\textbf{\Agipixs(Ours)} & SW and HW & \textcolor{green}{\cmark} & \textcolor{green}{\cmark}\textcolor{green}{\cmark} & \textcolor{green}{\cmark} & PX4 & $2{,}418$ & \textcolor{green}{\cmark} & \textcolor{green}{\cmark} & \textcolor{green}{\cmark}& $\approx3.50$ & $\approx495$ \\
        	\bottomrule
        \end{tabular}
        }
    \caption{
    Comparison of consumer and research platforms by onboard compute, agility, and sensing. Criteria include openness, ROS~2 support, simulation (double ticks denote photorealism), UI, CPU~performance ({\small\protect\url{https://www.cpubenchmark.net}}), and GPU availability. Agility is measured by thrust-to-weight; diagonal span is in flight configuration. (*conditionally open-source)
    }
    \label{fig:comparison}
    \vspace*{-12pt}
\end{figure*}

%
%
\subsection{Available Platforms}\label{subsec:related.platforms}
Figure~\ref{fig:comparison} summarizes the key features of \Agipixs and compares it with representative research and industrial platforms.

Commercial platforms such as DJI Matrice 400 \cite{djiMatrice400Specs2026} and Skydio X10 \cite{skydioX102026} offer mature sensing and autonomy but are large and better suited for outdoor missions. The Flyability Elios~3 \cite{flyabilityElios32022} targets confined inspection with protective structures and 3D LiDAR, yet all remain proprietary, limiting research extensibility and algorithm validation.

Open research platforms are more extensible. FLA Quad \cite{Mohta18jfr} and MRS-UAV \cite{Baca2021jirs} target GPS-denied navigation and mapping with PX4 \cite{meier2015px4}, CPU-only compute, cameras, and LiDAR, but the added payload increases size and weight, reducing thrust-to-weight ratio (TWR) and limiting close-proximity operation.

Agilicious \cite{Foehn2022Agilicious} prioritizes compactness and high TWR for aggressive flight, but its tight integration limits sensor expansion. OmniNxt \cite{liu2024omninxt} is smaller with omnidirectional perception, yet lacks 3D LiDAR, reducing mapping precision.

Across most open platforms, limited onboard GPU capability restricts real-time learning-based inspection and perception. \Agipixs combines 3D LiDAR, redundant depth and inertial sensing, and a capable GPU in a compact form factor, enabling robust indoor mapping and exploration with reproducible containerized deployment.
%
\subsection{Perception, State Estimation, and Mapping}\label{subsec:related.perception}
Fast, reliable state estimation underpins precise mapping. Prior work spans tightly-coupled factor-graph fusion (LIO-SAM \cite{shan2020lio}), direct point-to-map registration with efficient incremental data structures (FAST-LIO2 \cite{xu2022fast}), continuous-time trajectory estimation with higher-order motion models and observer-based stability (DLIO \cite{chen2022dlio}), and environment-adaptive LiDAR--inertial mapping with observability-aware segmentation and multi-resolution voxelization (Adaptive-LIO \cite{zhao2024adaptive}). Robustness improves with redundant perception pipelines and filtering when multiple sensors are available \cite{kuruppu2024robust}.

\subsection{Planning and Control}\label{subsec:related.planning}
\textbf{Planning:} Early quadrotor planning pipelines often relied on differential flatness and polynomial trajectory optimization (e.g., minimum-snap), which enabled smooth, dynamically feasible trajectories at high update rates \cite{mellinger2011minsnap}. Recent work expanded these foundations toward time-optimal, perception-aware local planning in clutter. In this direction, ViGO and EGO-Planner introduce ESDF-free, gradient-based local planners for agile flight in cluttered environments \cite{xuVigoPlanner2026, zhou2021egoplanner}. 

\textbf{Control:} Most real platforms still rely on a cascaded architecture with a PID-based attitude-rate inner loop for robustness and ease of tuning \cite{meier2015px4}. On top of this, advanced control approaches improve performance under constraints and disturbances, including MPC formulations \cite{lu2022onmpc} for time-optimal flight.

\textbf{Data-driven navigation policies:} Learning-based policies are increasingly used to augment or replace classical pipelines, enabling perception-aware, minimum-time flight and improved safety in cluttered scenes, with evidence of sim-to-real transfer at scale \cite{song2023perceptionaware,xu2025navrl}. Data-centric studies further quantify how synthetic vs. real data and scale impact navigation performance in unknown environments \cite{suomela2025synthetic,suomela2026data}. The modular \Agiautonomys lets \Agipixs adopt, validate, and deploy these methods in relevant scenarios.

\subsection{Simulation}\label{subsec:related.sim}
Photorealistic and physics-aligned simulators reduce development cost and risk. The aerial simulation landscape highlights that a large fraction of aerial robotics simulators are built around Gazebo, which is generally sufficient for dynamics and ROS integration but is not photorealistic \cite{furrer2016rotors}. In contrast, several simulators target higher-fidelity visuals by leveraging game engines. AirSim \cite{shah2017airsim} uses Unreal Engine, while Flightmare \cite{song2021flightmare} uses Unity to enable photorealistic rendering for perception-driven research in custom-built pipelines but lacks ROS~2 support.

The Isaac Sim ecosystem provides physics-based rendering and GPU-accelerated physics, while Pegasus enables PX4 SITL integration inside Isaac Sim \cite{jacinto2024pegasus}. \Agisims builds on this capability by implementing a digital twin of \Agipixs in Isaac Sim and sharing the same containerized autonomy stack in simulated and real flights.

\subsection{User interface}\label{subsec:related.ui}
Operator-facing UIs are typically delivered through ground control stations (GCS) that combine mission specification, real-time telemetry/health monitoring, and safety-critical handover between autonomy levels. Modern GCSs are largely map-centric, increasingly include decision-support tools, and must manage workload as supervision scales to multiple vehicles \cite{Zhang2024InterfaceWorkload}. Trends toward collaborative control, cloud-enabled thin clients, and UTM integration emphasize clear communication of automation state, intent, and constraints \cite{DiGregorio2021HumanGCS}.

In critical-asset inspection, UIs are vital for validating coverage, assessing map quality, and intervening when sensing degrades. Human-drone interaction work highlights the need to expose autonomy and safety boundaries to reduce workload and improve trust \cite{Hayat2016SurveyHDI}. These findings motivate \Agiuis as a lightweight, integrated mission-control and monitoring interface that aligns autonomy state with operator actions.

\section{\Agipixs PLATFORM}\label{sec:platform}
\subsection{System Overview} \label{sec:platform.overview}
\begin{figure*}[!ht]
        \centering
        
        \caption{System overview of the \Agipixs stack. \Agiautonomys runs modular ROS~2 components on the companion computer. Flight-state and setpoint topics are bridged to PX4 via native DDS in both simulation and real flights. An external ROS~2 logger records system telemetry. \Agiuis provides operator interaction, logging, and mission commands over a MQTT \cite{holmqvist1994visually}.}
        \label{fig:sys_overview}
        \vspace*{-12pt}
\end{figure*}
\Agipixs is organized into four interacting subsystems (Fig.~\ref{fig:sys_overview}). The \Agihws hardware platform and \Agisims simulation platform share \Agiautonomys, the ROS~2 autonomy pipeline comprising estimation, a map manager, a planner, and a controller. The controller publishes setpoints and receives flight-state feedback from PX4 via native DDS. In simulation, \Agisims couples PX4 SITL with a photorealistic Isaac Sim digital twin, while in real flights PX4 runs on the \Agihw. \Agiuis provides operator interaction (GUI), backend services, and logging, and interfaces with \Agiautonomys through an MQTT bridge \cite{ika_mqtt_client2026} that carries mission commands and returns status products (state, map, and POV imagery). Finally, a logger records ROS~2 topics and telemetry for offline analysis and reproducibility.

\subsection{\Agihw \ Hardware Design} \label{sec:platform.hw}

\subsubsection{Mechanical Architecture}
The \Agipixs hardware platform is designed for safe operation near structures and within narrow passages while retaining 3D LiDAR capability. The frame constrains the diagonal motor-to-motor span to \SI{438}{\milli\meter}, with a maximum width of \SI{372}{\milli\meter} and a \SI{495}{\milli\meter} diagonal including guards. This enables passage through typical \SI{800}{\milli\meter} doors with a maneuvering margin. Propulsion is sized to yield a static thrust-to-weight ratio of 3.5:1 at full payload. The LiDAR is mounted at a 45-degree angle and protected within the carbon-fiber shell with minimal occlusion and vibration damping. Secondary sensors can be swapped between missions depending on task requirements. An overview of the components is given in Table~\ref{tab:hw_components}.
\begin{table}[!ht]
    \centering
    \footnotesize
    \def\arraystretch{1.2}
    \begin{tabularx}{\linewidth}{l|l|X}
        \toprule
        Component & \parbox{1.8cm}{Product} & Specification \\
        \midrule
        Frame & Custom open-source & \SI{4}{\milli\meter} carbon fiber \\
        Motor & T-Motor Slatts 2306 & 23$\times$\SI{6}{\milli\meter} stator, \SI{2400}{\kilo\volt}, \SI{758}{\watt}  \\
        Propeller & \parbox{1.8cm}{Azure Power SFP5148} & \SI{5.1} inch length and \SI{4.8} inch pitch \\
        Battery & Tattoo G-Tech 4500 & 6$\times$ \SI{3.7}{\volt}, \SI{4500}{\milli\ampere\hour} \\
        Flight Controller & Pixhawk Orange & Built in redundancy \\
        Motor Controller & F55A Pro II 3-6S & DShot protocol, 4$\times$ \SI{60}{\ampere} \\
        Compute Unit & \parbox{2.0cm}{nVidia Jetson Orin Nx (Super)} & 8$\times$ A78 \SI{2.0}{\giga\hertz}, \SI{16}{\giga\byte}, 157 TOPS \\  
        \midrule
        LiDAR & Livox MID 360 & \SI{50}{\meter} at 360°$\times$59° FOV \\
        IMU & Pixhawk Orange & Isolated and triple redundant\\
        Optical flow & HereFlow PX4 & Redundant velocity measurement \\
        Depth (Opt.) & RealSense D455 & \SI{6}{\meter} m at 87°$\times$58° FOV \\
        RGB (Opt.) & Arducam OG02B10 & Global Shutter \\
        Radiation (Opt.) & DFrobot Gravity & Ionizing Radiation Detector \\
        \bottomrule
    \end{tabularx}
    \caption{Overview of the components of the flight hardware design.}
    \label{tab:hw_components}
    \vspace*{-15pt}
\end{table}
\subsubsection{Sensors and Hardware Synchronization}
The primary sensors of the platform are the LiDAR and IMU, which are used for LiDAR--inertial odometry (LIO) state estimation. Accurate synchronization between these sensors is critical for reliable estimation. We achieve this using the pulse-per-second (PPS) synchronization capability of the Livox Mid-360 LiDAR. The Pixhawk, which houses the IMU, acts as the master clock, and both the companion computer and LiDAR are synchronized to it. An ESP32 connected to the Pixhawk via MAVLink generates the timing signal required by the LiDAR. An overview of the method is shown in Fig.~\ref{fig:hw_sync}. USB~3.0, CAN, UART, RS-232, and SPI interfaces are available for optional secondary sensors.

\begin{figure}[!ht]
        \centering
        
        \caption{Hardware time synchronization pipeline. The Pixhawk (IMU) provides the master clock; the LiDAR is synchronized via PPS, with an ESP32 generating the required timing signal.}
        \label{fig:hw_sync}
        \vspace*{-12pt}
\end{figure}

\subsection{\Agiautonomy: Modular Software Framework} \label{sec:platform.sw}
\Agiautonomys is organized as a set of ROS 2 packages and runtime services that communicate over ROS 2. To enable reproducible deployment, \Agiautonomys lives in a container image and is launched through a unified orchestration. This isolates dependencies, makes experiments portable across compute targets, and allows switching between sim and hardware by changing only the configuration

\noindent\textbf{Middleware and interfaces:} We use Micro XRCE-DDS \cite{PX4_ROS2_bridge} to interface directly with PX4 uORB topics. Safety-critical primitives remain in PX4, while higher-level autonomy runs onboard the companion computer. A thin interface layer \cite{PX4_ROS2_Control_Interface} translates between ROS~2 messages and validated PX4 setpoint streams.

\subsubsection{Perception: State Estimation and Mapping}
\Agiautonomys provides a LiDAR--inertial state-estimation and mapping pipeline for GPS-denied indoor environments. The default configuration uses a modified Adaptive-LIO \cite{zhao2024adaptive} with an EKF that fuses the IMU to improve robustness and update rate.

For navigation in cluttered industrial sites, the perception stack flags dynamic obstacles using LV-DOT \cite{LV-DOT}. The local environment is maintained as a 3D occupancy structure and the global map as a voxel grid. These feed the planner and \Agiui, while higher-resolution maps are recorded for offline inspection.

\subsubsection{Planning and Control} \label{sec:platform.sw.plan_ctrl}
\Agiautonomys exposes multiple flight modes that separate operator intent, autonomy level, and safety constraints, enabling staged bring-up while reusing PX4 safeguards. Beyond PX4's standard modes, the stack provides four autonomy modes: \emph{Twist control} (direct velocity commands from \Agiui), \emph{Goal control} (\Agiuis controlled goal pose with obstacle avoidance), \emph{Navigation control} (global waypoint/trajectory following), and \emph{Exploration control} (closest-frontier autonomy).

Trajectory generation uses a local ViGO planner \cite{xuVigoPlanner2026} that produces dynamically feasible polynomial trajectories in the current occupancy map. The resulting trajectory is tracked by an on-manifold MPC \cite{lu2022onmpc}, which outputs smooth attitude/thrust references streamed to PX4 as trajectory setpoints at a fixed rate.

\textbf{Data-driven navigation policies:} The modular design and separated control modes of \Agiautonomys enable learning-based navigation. Following Section~\ref{subsec:related.planning}, we evaluate a learned policy by deploying the Fast Appearance-Invariant Navigation Transformer (FAINT) \cite{suomela2025synthetic} onboard \Agihw. The policy, trained in simulation, transfers zero-shot to the platform, illustrating the adaptability enabled by \Agiautonomy.

\subsubsection{Data Logging}
Reliable data logging is mission-critical for inspection tasks. ROS~2 bags can grow quickly, become corrupted, and consume system memory. We provide \textit{agi\_logger} \cite{Kuruppuarachchi2026agi_logger}, an open-source package for reliable logging and TCP file transfer that uses \texttt{.mcap} storage with autostart, memory/time limits, and lossless segmented recording. \texttt{.mcap} log files enable offline inspection using tools such as Foxglove \cite{foxglove2026}.

\subsection{\Agisim: Digital Twin} \label{sec:platform.sim}

\subsubsection{Simulation Environment and Workflow}
\Agisims provides a photorealistic digital twin if the \Agihw. As summarized in Fig.~\ref{fig:sys_overview}, Isaac Sim renders the environment and simulates the onboard sensors with time-stamped outputs. PX4 software-in-the-loop (SITL) is handled through the Pegasus interface \cite{jacinto2024pegasus} communicates via DDS, so that the same ROS~2 topics are available to \Agiautonomys as in real flight.

\noindent\textbf{Workflow.} A typical experiment proceeds as follows: (i) launch Isaac Sim with the scene, robot, sensor configuration and PX4 SITL, (ii) start the ROS~2 bridge, (iii) launch the \Agiautonomys containers, and (iv) visualize and supervise the run via \Agiui/Foxglove. The same mission definitions are used across sim and real flights, which supports rapid iteration while keeping deployment consistent.

\subsubsection{Reproducibility and Configuration Parity}
To reduce sim-to-real drift, \Agisims enforces configuration parity at three levels. 
\emph{Sensor parity} is maintained by matching calibration and noice parameters frames and topic conventions with the hardware setup. 
\emph{Timing parity} is achieved by propagating simulation time consistently to ROS~2. 
\emph{Software parity} is ensured by running the exact same container images and launch files in both environments.

% \begin{figure*}[t]
%   \centering
%   \includegraphics[width=\textwidth]{images/agiui.png}
%   \caption{This is the complete overview of the AgiUI where the user can see different perspectives of the robots it is controlling, including a top view, a side view, and a third-person view.}
%   \label{fig:ui_complete_agiu}
% \end{figure*}

\subsection{AgiUI: User Interface}\label{sec:platform.ui}

\Agiuis is the operator-facing interface that closes the loop between mission intent and the onboard autonomy stack (Fig.~\ref{fig:sys_overview}). We implement \Agiuis as a lightweight web application that bridges commands and status through a low-bandwidth MQTT channel \cite{Hu2021CloudStation}. The UI server receives state, map updates, POV imagery, and payload readings over the MQTT channel. User commands and motion bounds are sent back to be received by the robot-side UI backend, which translates them back to ROS~2 topics.

The GUI is organized around (i) a fleet overview and (ii) synchronized spatial products. The fleet panel lists all active robots under supervision using a common abstraction of connection state, autonomy mode, and basic health indicators. A 3D mapping view provides a shared, joint reconstruction from the different robots, enabling operators to inspect explored regions, verify coverage, and contextualize robot poses and trajectories. For radiological inspection, \Agiuis additionally renders a radiation map aligned with the shared environment representation, supporting rapid identification of hotspots and informing viewpoint replanning. Per-robot control tabs expose mission specification (geofences, waypoints, and inspection tasks) and teleoperation primitives, with explicit mode switching (manual/assisted/autonomous) to support safe handover procedures. 

%Beyond robot control, \Agiuis includes a Human-Robot Interaction (HRI) monitoring panel to support user-centric supervision. Building on our prior work on cognitive-load dynamics in teleoperation \cite{GarciaCardenas2024CognitiveLoadTeleop}, this panel can ingest physiological streams (e.g., heart-rate variability, electrodermal activity/GSR, and eye-based measures) and display online indicators of cognitive load and trust alongside mission context. These signals are logged with the rest of the system telemetry, enabling post-hoc analysis and future closed-loop policies that adapt autonomy level and information presentation to the operator's state.

\section{RESULTS}\label{sec:results}
This section summarizes inspection- and mapping-focused experiments conducted in both simulation (\Agisim) and real-world flights and outlines the evaluation protocol used during ENRICH~2025.

\begin{table}[!ht]
    \centering
    \footnotesize
    \def\arraystretch{1.2}
    \begin{tabularx}{\linewidth}{l|r|r}
        \toprule
        \parbox{3.3cm}{\textbf{Trajectory}} 
        & \parbox{2cm}{\centering\textbf{AgiSIM ATE (m)}} 
        & \parbox{2cm}{\centering\textbf{AgiREAL ATE (m)}}\\
        \midrule
        Lemniscate  & 0.0637 & 0.1404 \\
        Up Down Spiral  & 0.0368 & 0.1049 \\
        \bottomrule
    \end{tabularx}
    \caption{Trajectory-tracking performance comparison between AgiSIM and AgiREAL across different trajectories.}
    \label{tab:rmse_results}
    \vspace*{-12pt}
\end{table}

\begin{figure}[t]
        \centering
        
        \caption{Trajectory-tracking comparison of Ground Truth, \Agisim, and \Agihws in two trajectories at 6 m/s maximum velocity; Up down spiral and lemniscate: (1) spiral in the $x$--$y$ plane, (2) spiral in the $y$--$z$ plane, and (3) lemniscate in the $x$--$y$ plane.}
        \label{fig:result_tracking}
        \vspace*{-13pt}
\end{figure}
\subsection{Trajectory tracking performance}\label{subsec:results_trajectory}
We evaluate trajectory-tracking accuracy in both \Agisim{} and \Agihw{} using two representative paths: a lemniscate and an up--down spiral (Fig.~\ref{fig:result_tracking}). As described in Sec.~\ref{sec:platform.sw.plan_ctrl}, the predefined polynomial trajectories are tracked by an on-manifold MPC \cite{lu2022onmpc} that produces attitude setpoints for the low-level controller. Real-world poses are measured by a VICON system. Each run is executed at a maximum linear speed of \SI{6}{\meter\per\second} and a maximum linear acceleration of \SI{5}{\meter\per\second}, and tracking performance is reported as ATE RMSE with respect to the ground-truth trajectory (Table~\ref{tab:rmse_results}).

Across both trajectories, \Agipix{} maintains sub-decimeter tracking error in simulation and low-decimeter error on hardware. In \Agisim{}, RMSE is \SI{0.0637}{\meter} (lemniscate) and \SI{0.0368}{\meter} (up--down spiral); on \Agihw{}, RMSE is \SI{0.1404}{\meter} and \SI{0.1049}{\meter}, respectively. Despite the expected sim-to-real gap from unmodeled disturbances and sensing/actuation effects, tracking remains stable under fast direction changes and altitude variations.

\begin{figure}[ht!]
        \centering
        
        \caption{Left: AKW Zwentendorf, Right: \Agipix during the various stages of the trial.}
        \label{fig:enrich_team}
\end{figure}
\begin{figure}[t]
        \centering
        
        \caption{Representative ENRICH~2025 mapping output.}
        \label{fig:enrich_mapping}
\end{figure}
\begin{figure}[t]
        \centering
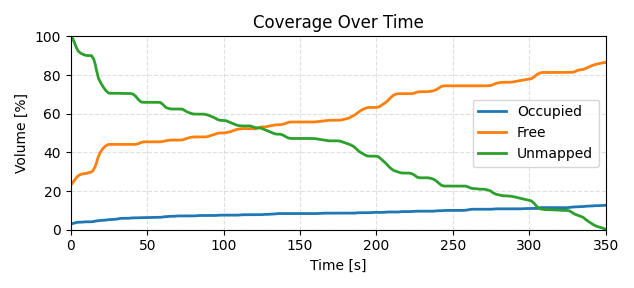
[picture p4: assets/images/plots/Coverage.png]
        
        \caption{Percentage of free, occupied, and unmapped volume over the total exploration time for the exploration mode using the closest-frontier method for the given map}
        \label{fig:result_explore}
        \vspace*{-6pt}
\end{figure}

\subsection{Mapping Results}\label{subsec:results.mapping}
We report mapping fidelity (IoU) and exploration coverage over time (Fig.~\ref{fig:result_explore}) in a representative indoor environment. The experiment uses a modified Adaptive-LIO \cite{zhao2024adaptive} with Closest Frontier planning \cite{xu2021CFExplore}. We achieved an IoU of 0.96 between the occupancy grid and the ground-truth map over the explored region.

We validated \Agipixs at ENRICH~2025~\cite{europeanroboticsENRICH2025} on a large-scale indoor mapping task (Fig.~\ref{fig:enrich_team}). The \Agihw::UAV runs were complemented by a \Agihw::UGV for extended floor-level coverage. The mission reached 72\% of the planned flight distance before a communication failure; Fig.~\ref{fig:enrich_mapping} shows the resulting map.

\begin{figure}[!ht]
    % \centering
    % \includegraphics[
    % trim={3cm 5cm 3cm 3cm}, clip,
    % width=\linewidth]{images/motion_trails/drone_fixed.png}
    \centering
    \includegraphics[
    trim={0cm 0.3cm 0cm -0.4cm}, clip,
    width=1.0\linewidth]{images/plots/faint_trajectories.png}
    
    \caption{ Drone trajectory relative to the mapping trajectory when controlled by FAINT \cite{suomela2025synthetic}, a learning-based visual navigation method. The drone successfully reached the goal on the left trajectory, but missed it on the right.}
    \label{fig:drone_trajectories}
    \vspace*{-12pt}
\end{figure}

\subsection{Learning-Based Navigation Results}\label{subsec:results.learning}
We evaluated a learned visual navigation policy on the \Agipixs drone without retraining. The FAINT model \cite{suomela2025synthetic} was deployed onboard to control forward velocity and yaw rate at fixed altitude. In real-wprld experiments (Fig.~\ref{fig:drone_trajectories}), the policy transferred across embodiment, achieving \SI{1.07}{\meter} RMSE on a successful run and \SI{1.42}{\meter} RMSE on a more challenging route, with \SI{120}{\milli\second} inference latency on the Jetson Orin NX.

These results show \Agipix's ability to run state-of-the-art learning-based methods that require fast visual feature computation, and to serve as a validation platform for learning-based navigation.

\subsection{System Utilisation on the Onboard Compute Unit}

Table \ref{tab:utilization_table} reports the average CPU and GPU utilisation of \Agiautonomy\ on the Jetson Orin NX Super 16 GB. The system uses 41\% of the CPU and 37\% of the GPU, leaving 59\% and 63\% free resources, respectively.

Overall, the results indicate substantial computational headroom, supporting real-time operation and future scalability.

\begin{table}[!ht]
    \centering
    \footnotesize
    \def\arraystretch{1.2}
    \begin{tabularx}{\linewidth}{l|r|r}
        \toprule
        \parbox{3.3cm}{\textbf{Software Component}} & \parbox{2cm}{\centering\textbf{CPU Utilisation (\%)}} & \parbox{2cm}{\centering\textbf{GPU Utilisation (\%)}}\\
        \midrule
        AdaptiveLIO & 13 & 5 \\
        Livox Driver & 9 & 2 \\
        Map Manager & 4 & 20 \\
        Ego planner & 1 & 10 \\
        Autonomous flight & 10 & 0 \\
        Controller & 1 & 0 \\
        PX4 ROS~2 Interface & 1 & 0 \\
        uXREC-DDS & 1 & 0 \\
        \midrule
        \textbf{Free Resources} & \textbf{59} & \textbf{63} \\
        \bottomrule
    \end{tabularx}
    \caption{Average system utilisation on Jetson Orin NX Super 16 GB by \Agiautonomy.}
    \label{tab:utilization_table}
    \vspace*{-12pt}
\end{table}

\subsection{Adaptation of \Agipix}
\begin{figure}[ht!]
        \centering
        
        \caption{\Agipixs supports heterogeneous hardware deployments. \Agihw::UAV and \Agihw::UGV, shown here, were deployed in ENRICH~2025~\cite{enrich2025raicam}.}
        \label{fig:adaptations}
        \vspace*{-12pt}
\end{figure}
\Agihws hardware design supports interchangeable platform configurations. We provide two variants \Agihw::UAV and \Agihw::UGV as shown in Fig.~\ref{fig:adaptations}, both validated in real-world experiments during ENRICH~2025~\cite{enrich2025raicam}. The architecture shares \Agiautonomys, differing only at the vehicle dynamics and actuation interface, thereby extending the framework beyond a single morphology while maintaining consistent mission and logging workflows.

\section{DISCUSSION}\label{sec:discussion}
\Agipix is designed around a co-design principle: sensing, compute, and autonomy are specified jointly so that the same pipeline can run in both a photorealistic digital twin (\Agisim) and on the real vehicle. The ENRICH~2025 mapping task highlights the practical value of this approach for inspection scenarios, where rapid iteration, reproducible deployment, and robust state estimation are as important as raw flight agility.

\noindent\textbf{Trade-offs.} The compact airframe and protective shell improve close-proximity operation, but the rigid structure increases the risk of frame damage in the event of a hard collision. The compact integration also limits the size and placement of additional sensor modules.\\
\noindent\textbf{Limitations.} The current hardware platform supports connectivity over Wi-Fi~6 and LTE, which can be limiting in extreme environments (e.g., subterranean tunnels or nuclear power plants). Swarm and collaborative mapping capabilities are not yet released.\\
\noindent\textbf{Next steps.} Future work will (i) improve the hardware design by introducing a more compliant impact structure, (ii) expand the digital-twin asset pipeline and sensor-noise models to better match real sites, (iii) improve connectivity by introducing local node-based mesh networking, (iv) introduce cognitive, measurement-induced motion bounds in \Agiuis to improve operator trust and HRI, and (v) add swarm and collaborative mapping capabilities to \Agiautonomy.\\

\section{CONCLUSION}\label{sec:conclusion}
We presented \Agipixs, an open, compact aerial robotics platform for indoor mapping and inspection that bridges simulation and reality through a hardware-synchronized active sensing platform (\Agihw), a containerized ROS~2 autonomy stack (\Agiautonomy), a photorealistic Isaac Sim digital twin (\Agisim), and an operator-facing interface (\Agiui). The platform combines powerful onboard GPU compute with low-level PX4 control to support reproducible deployment and rapid sim-to-real iteration. We report performance focusing on trajectory tracking accuracy, mapping fidelity, and inspection coverage, and we report field validation on the ENRICH~2025 mapping task. By open sourcing all hardware, software, and documentation, we aim to lower financial and engineering barriers and accelerate reproducible research in indoor aerial robotics.

\section*{ACKNOWLEDGMENT}
We acknowledge RAICAM, MSCA HORIZON EU funding. We thank contributors to the open-source ecosystem leveraged by \Agipix.

\bibliographystyle{ieeetr}
\bibliography{ref}
\end{document}

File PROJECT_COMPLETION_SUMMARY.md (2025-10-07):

# Agipix GitHub Pages - Project Completion Summary

## 🎯 Mission Accomplished

Successfully built a complete GitHub Pages website for the Agipix project with all requested features.

## ✅ Requirements Met

### 1. Dark Theme ✓
- Deep black background (#0a0a0a)
- Dark red accents (#8b1a1a, #b32424)
- Futuristic, professional design
- Custom CSS with CSS variables for easy theming

### 2. Typography ✓
- **Orbitron font** for "AGIPIX" header (Osake alternative from Google Fonts)
- System fonts for body text (optimal performance)
- Professional, tech-inspired aesthetic

### 3. Sim-to-Real Emphasis ✓
- Split sections comparing simulation vs real hardware
- Digital twin concept highlighted throughout
- Side-by-side images (sim.png and real.jpg)
- "Zero code changes" messaging emphasized

### 4. Documentation Integration ✓
- Content pulls from `doc/` directory:
  - `doc/sim/1_setup_sim.md` → Simulation Setup
  - `doc/real/1_hardware_assembly.md` → Hardware Assembly
  - `doc/real/2_flashing_hardware.Md` → Flashing Guide
  - `doc/real/3_software_setup.md` → Software Setup
  - `doc/autonomy/2_planning_control.md` → Autonomy Framework
  - `bom/BOM.md` → Bill of Materials

### 5. Image Assets ✓
- Uses images from `assets/images/`:
  - exploded.gif (hero banner)
  - sim.png (simulation screenshot)
  - real.jpg (real hardware photo)

### 6. Navigation ✓
- Easy access to setup documentation
- Direct links to GitHub repository
- Sticky header with navigation bar
- Footer with contact information

### 7. Project Showcase ✓
- 6 key highlights in grid layout
- Quick start section with 3 categories
- Professional presentation
- Responsive design for all devices

## 📦 Deliverables

### Website Files (15 files)
1. `_config.yml` - Jekyll configuration
2. `_layouts/default.html` - Main page layout
3. `_layouts/doc.html` - Documentation layout
4. `assets/css/style.scss` - Dark theme CSS (10KB+)
5. `index.html` - Homepage
6. `docs/sim-setup.md` - Simulation setup
7. `docs/hardware-assembly.md` - Hardware assembly
8. `docs/flashing-hardware.md` - Flashing guide
9. `docs/software-setup.md` - Software setup
10. `docs/autonomy.md` - Autonomy framework
11. `bom.md` - Bill of Materials
12. `Gemfile` - Ruby dependencies
13. `.gitignore` - Updated with Jekyll artifacts

### Documentation Files (3 files)
14. `GITHUB_PAGES_README.md` - Setup & customization guide
15. `SITE_SUMMARY.md` - Implementation details
16. `DEPLOYMENT_GUIDE.md` - Quick start deployment

## 🎨 Design Highlights

### Color Palette
- **Primary Background**: #0a0a0a (deep black)
- **Secondary Background**: #1a1a1a (dark gray)
- **Accent Red**: #8b1a1a (dark red)
- **Accent Red Light**: #b32424 (bright red)
- **Text Primary**: #e0e0e0 (light gray)
- **Text Secondary**: #a0a0a0 (medium gray)

### Special Effects
- Animated glow on "AGIPIX" header
- Hover effects on cards and buttons
- Smooth transitions (0.3s ease)
- Custom dark-themed scrollbar
- Box shadows with red glow

### Typography
- **Header Font**: Orbitron (Google Fonts)
- **Body Font**: System font stack
- **Code Font**: Courier New monospace

## 🚀 Deployment Status

### Ready for Production ✓
- ✅ Site builds successfully with Jekyll 4.4.1
- ✅ All pages render correctly
- ✅ All links functional
- ✅ Images load properly
- ✅ Responsive on mobile/tablet/desktop
- ✅ No build errors or warnings

### How to Deploy
1. Go to Repository Settings → Pages
2. Source: Select branch (e.g., `main`), folder `/ (root)`
3. Click Save
4. Wait 1-2 minutes for build
5. Visit: https://sasakuruppuarachchi.github.io/agipix/

## 📊 Site Structure

```
Homepage
├── Hero Section (exploded.gif banner)
├── Sim-Real Split (side-by-side comparison)
├── Key Highlights (6 feature cards)
├── Quick Start (3-column grid)
└── Repository Layout

Documentation Pages
├── Simulation Setup
├── Hardware Assembly
├── Flashing Hardware
├── Software Setup
└── Autonomy Framework

Bill of Materials
└── Complete component list

Navigation
├── Sticky Header ("AGIPIX" with glow)
├── Navigation Bar (6 links)
└── Footer (contacts, acknowledgment)
```

## 🎯 Key Features

1. **Sim-to-Real Deployability** - Identical ROS 2 containers
2. **Open-Source Platform** - Full BOM, CAD, software stack
3. **Modular Autonomy Stack** - ROS 2-based architecture
4. **Small Form Factor** - 438×372 mm, TWR ≈ 2.98:1
5. **Extensive Sensor Suite** - 3D LiDAR, RGB camera, IMU
6. **Modular Hardware Design** - Layered decks for upgrades

## 📝 Testing Results

### Build Testing ✓
- Jekyll 4.4.1 builds successfully
- No errors or warnings
- All pages generated correctly
- CSS compiled properly

### Visual Testing ✓
- Dark theme renders correctly
- Red accents display properly
- Orbitron font loads successfully
- Images display from assets/images/
- Responsive layout works on all screen sizes

### Functional Testing ✓
- All navigation links work
- Documentation pages render markdown correctly
- Code blocks are syntax highlighted
- Tables display properly
- Buttons have hover effects

### Performance ✓
- Single CSS file (minified)
- System fonts for body (no extra downloads)
- Optimized images from repository
- No JavaScript dependencies
- Fast load times

## 📚 Documentation Provided

1. **DEPLOYMENT_GUIDE.md** - Quick start guide for deployment
2. **GITHUB_PAGES_README.md** - Complete setup documentation
3. **SITE_SUMMARY.md** - Detailed implementation notes
4. **PROJECT_COMPLETION_SUMMARY.md** - This file

## 🎉 Project Complete

The Agipix GitHub Pages website is:
- ✅ Fully functional
- ✅ Dark themed with red accents
- ✅ Futuristic and professional
- ✅ Emphasizes Sim-to-Real deployability
- ✅ Uses Orbitron font for headers
- ✅ Integrates documentation from doc/
- ✅ Uses images from assets/images/
- ✅ Has easy navigation to setup docs and GitHub
- ✅ Project showcase style presentation
- ✅ Ready for immediate deployment

**Status**: PRODUCTION READY 🚀

---

**Next Step**: Enable GitHub Pages in repository settings and share the URL!

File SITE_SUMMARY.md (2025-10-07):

# Agipix GitHub Pages Site - Implementation Summary

## Overview

A fully functional, dark-themed GitHub Pages website has been created for the Agipix project. The site emphasizes the project's unique Sim-to-Real deployability with a futuristic, professional design featuring dark red accents.

## Key Features Implemented

### 1. Design & Theme
- **Dark Theme**: Deep black background (#0a0a0a) with dark red accents (#8b1a1a, #b32424)
- **Futuristic Typography**: Orbitron font (Osake alternative) for the "AGIPIX" header
- **Digital Twin Concept**: Split sim/real sections emphasizing the seamless deployability
- **Responsive Design**: Mobile-friendly layout that adapts to different screen sizes
- **Glowing Effects**: Animated text shadows and hover effects for the header

### 2. Site Structure

```
agipix/
├── _config.yml                 # Jekyll configuration
├── _layouts/
│   ├── default.html           # Main layout with header, navigation, footer
│   └── doc.html               # Documentation page layout
├── assets/css/
│   └── style.scss             # Dark theme with CSS variables
├── index.html                 # Homepage with hero section, highlights
├── docs/
│   ├── sim-setup.md          # Simulation setup guide
│   ├── hardware-assembly.md   # Hardware assembly guide
│   ├── flashing-hardware.md   # Flashing guide
│   ├── software-setup.md      # Software setup guide
│   └── autonomy.md            # Autonomy framework documentation
├── bom.md                     # Bill of Materials
├── Gemfile                    # Ruby dependencies
├── GITHUB_PAGES_README.md     # Setup documentation
└── .gitignore                 # Excludes Jekyll build artifacts
```

### 3. Homepage Components

#### Hero Section
- Large animated banner (exploded.gif)
- Compelling project description
- "View on GitHub" and "Get Started" CTAs

#### Sim-Real Split Section
- Side-by-side comparison of simulation and real hardware
- Visual emphasis on identical deployability
- Direct links to setup guides

#### Key Highlights Grid
- 6 feature cards highlighting:
  1. Sim-to-Real Deployability
  2. Open-Source Platform
  3. Modular Autonomy Stack
  4. Small Form Factor
  5. Extensive Sensor Suite
  6. Modular Hardware Design

#### Quick Start Section
- Three-column grid for:
  - Simulation setup
  - Hardware build
  - Autonomy framework
- Links to all relevant documentation

#### Repository Layout
- Quick reference to project structure

### 4. Navigation
- Sticky header with glowing "AGIPIX" title
- Clean navigation bar with links to:
  - Home
  - Simulation Setup
  - Hardware Assembly
  - Autonomy Framework
  - BOM
  - GitHub Repository

### 5. Documentation Pages
All documentation pages feature:
- Clean, readable layout with dark theme
- Syntax-highlighted code blocks
- Properly styled tables and lists
- Links back to original repository docs
- "Back to Home" and "View on GitHub" buttons

### 6. Footer
- Contact information for authors
- Acknowledgment (RAICAM, MSCA HORIZON EU)
- License link
- Consistent styling across all pages

## CSS Variables Used

```css
--primary-bg: #0a0a0a          /* Main background */
--secondary-bg: #1a1a1a        /* Card/section backgrounds */
--accent-red: #8b1a1a          /* Primary accent */
--accent-red-light: #b32424    /* Lighter accent for text/links */
--accent-red-dark: #5a0f0f     /* Darker accent for borders */
--text-primary: #e0e0e0        /* Main text color */
--text-secondary: #a0a0a0      /* Secondary text */
--text-muted: #606060          /* Muted text */
--border-color: #2a2a2a        /* Border color */
--code-bg: #151515             /* Code block background */
```

## Typography

- **Header Font**: Orbitron (Google Fonts) - used for "AGIPIX" and section headers
- **Body Font**: System font stack for optimal performance
- **Code Font**: Courier New monospace

## Special Effects

1. **Glow Animation**: Header text pulses with red glow
2. **Hover Effects**: Cards and buttons lift on hover with shadow effects
3. **Smooth Transitions**: 0.3s ease transitions on interactive elements
4. **Custom Scrollbar**: Dark themed scrollbar matching the site design

## Documentation Integration

The site pulls content from the repository's `doc/` directory:
- `doc/sim/1_setup_sim.md` → Simulation Setup page
- `doc/real/1_hardware_assembly.md` → Hardware Assembly page
- `doc/real/2_flashing_hardware.Md` → Flashing Hardware page
- `doc/real/3_software_setup.md` → Software Setup page
- `doc/autonomy/2_planning_control.md` → Autonomy Framework page
- `bom/BOM.md` → Bill of Materials page

Each page includes:
- Summary of key information
- Links to complete documentation in the repository
- Proper formatting and styling

## Image Assets

The site uses images directly from the repository:
- `assets/images/exploded.gif` - Hero banner
- `assets/images/sim.png` - Simulation screenshot
- `assets/images/real.jpg` - Real hardware photo

## Responsive Design

Media queries ensure proper display on mobile devices:
- Single column layout for mobile
- Reduced font sizes
- Stacked navigation
- Full-width cards and sections

## Deployment Instructions

### Enabling GitHub Pages

1. **Navigate to Repository Settings**
   - Go to `https://github.com/SasaKuruppuarachchi/agipix/settings/pages`

2. **Configure Source**
   - Under "Source", select the branch (e.g., `main`)
   - Select folder: `/ (root)`
   - Click "Save"

3. **Wait for Deployment**
   - GitHub Actions will automatically build the site
   - Check the Actions tab for build progress
   - Site will be available at: `https://sasakuruppuarachchi.github.io/agipix/`

### Local Development

```bash
# Install dependencies
gem install --user-install bundler jekyll

# Navigate to repository
cd /path/to/agipix

# Build the site
export PATH="$HOME/.local/share/gem/ruby/3.2.0/bin:$PATH"
jekyll build

# Serve locally
jekyll serve --baseurl /agipix

# Open in browser
# http://localhost:4000/agipix/
```

## Files Created/Modified

### New Files
- `_config.yml` - Jekyll configuration
- `_layouts/default.html` - Main page layout
- `_layouts/doc.html` - Documentation layout
- `assets/css/style.scss` - Main stylesheet (10,778 characters)
- `index.html` - Homepage (4,953 characters)
- `docs/sim-setup.md` - Simulation setup documentation
- `docs/hardware-assembly.md` - Hardware assembly documentation
- `docs/flashing-hardware.md` - Flashing guide
- `docs/software-setup.md` - Software setup guide
- `docs/autonomy.md` - Autonomy framework documentation
- `bom.md` - Bill of Materials page
- `Gemfile` - Ruby dependencies
- `GITHUB_PAGES_README.md` - Setup guide
- `SITE_SUMMARY.md` - This file

### Modified Files
- `.gitignore` - Added Jekyll build artifacts

## Testing Results

✅ **Build Success**: Site builds without errors using Jekyll 4.4.1  
✅ **Local Preview**: Tested at `http://localhost:4000/agipix/`  
✅ **Page Rendering**: All pages render correctly with dark theme  
✅ **Navigation**: All links work correctly  
✅ **Responsive**: Layout adapts to different screen sizes  
✅ **Images**: All images load from `assets/images/`  
✅ **Typography**: Orbitron font loads and displays correctly  
✅ **CSS**: Dark theme with red accents renders perfectly  

## Browser Compatibility

The site uses modern CSS features but includes fallbacks:
- CSS Grid with fallback to flexbox
- CSS Variables with fallback colors
- Custom scrollbar (webkit only, degrades gracefully)

## Performance Optimizations

- System fonts for body text (no extra font download)
- Single CSS file (minified by Jekyll)
- Optimized images (using existing repository assets)
- No JavaScript dependencies (static site)

## SEO & Metadata

- Proper HTML5 semantic structure
- Meta description tags
- Title tags on all pages
- Alt text on images
- Structured headings (h1-h3)

## Accessibility

- High contrast dark theme (WCAG compliant)
- Semantic HTML structure
- Keyboard navigation support
- Focus indicators on interactive elements
- Alt text on all images

## Future Enhancements (Optional)

1. **Search Functionality**: Add Algolia or Lunr.js search
2. **Analytics**: Add Google Analytics or similar
3. **Social Meta Tags**: Add Open Graph and Twitter Card metadata
4. **Dark/Light Toggle**: Add theme switcher (currently dark only)
5. **Animation**: Add subtle scroll animations using AOS or similar
6. **Blog Section**: Add Jekyll blog for project updates

## Conclusion

The Agipix GitHub Pages site is complete and ready for deployment. It successfully:
- Captures the project's innovative Sim-to-Real approach
- Provides easy navigation to all documentation
- Features a professional, futuristic dark theme
- Emphasizes the digital twin concept with visual design
- Uses the Orbitron font for headers (Osake alternative)
- Integrates seamlessly with the existing repository structure

The site is production-ready and can be enabled immediately in the repository settings.

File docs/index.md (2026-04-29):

---
title: Agipix Documentation
layout: doc
permalink: /docs/
description: Start here to assemble the hardware, flash the Jetson, set up software, or run the simulation.
wip: true
---

# Documentation Hub

Agipix documentation is organized around the four platform blocks from the paper: real hardware, simulation, autonomy, and operator UI.

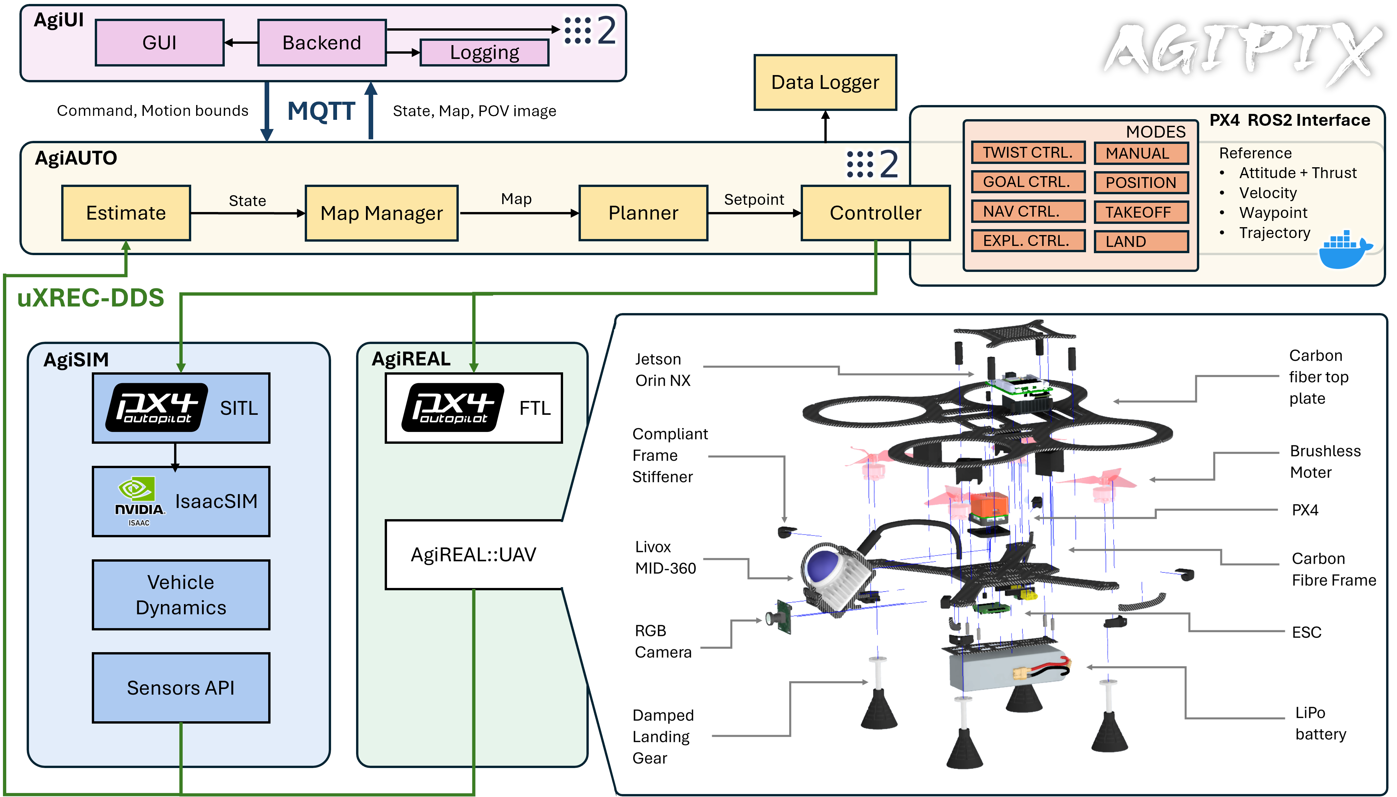
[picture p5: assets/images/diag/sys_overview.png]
System overview


Pick a scope to dive into. Each scoped section includes a sidebar with step-by-step pages.

<div class="quick-start-grid">
	<div class="quick-start-card">
		<h3>Real Hardware</h3>
		<p>Build, wire, flash, and validate the physical platform.</p>
		<ul>
			<li>Assembly and wiring</li>
			<li>Flashing Jetson & carrier</li>
			<li>Container and software setup</li>
		</ul>
		<p><a class="btn" href="{{ '/docs/real/' | relative_url }}">Real Docs →</a></p>
	</div>
	<div class="quick-start-card">
		<h3>Simulation</h3>
		<p>Use the digital twin in Isaac Sim before hardware deployment.</p>
		<ul>
			<li>Isaac Sim environment</li>
			<li>Containerized workflow</li>
			<li>PX4 SITL + ROS 2 bridge</li>
		</ul>
		<p><a class="btn" href="{{ '/docs/sim/' | relative_url }}">Sim Docs →</a></p>
	</div>
	<div class="quick-start-card">
		<h3>Autonomy</h3>
		<p>Perception, planning/control, and learning-based navigation.</p>
		<ul>
			<li>Perception pipeline</li>
			<li>Planning and control</li>
			<li>Data-driven policy integration</li>
		</ul>
		<p><a class="btn" href="{{ '/docs/autonomy/' | relative_url }}">Autonomy Docs →</a></p>
	</div>
	<div class="quick-start-card">
		<h3>User Interface</h3>
		<p>Mission supervision, teleoperation, and human-in-the-loop workflows.</p>
		<ul>
			<li>Teleoperation</li>
			<li>Exploration mode control</li>
			<li>Human-in-the-loop control</li>
		</ul>
		<p><a class="btn" href="{{ '/docs/ui/' | relative_url }}">UI Docs →</a></p>
	</div>
</div>

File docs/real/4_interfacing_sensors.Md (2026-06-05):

---
title: Interfacing PX4 and Sensors
layout: doc
nav_title: PX4 and Sensors
---

# Interfacing PX4 and Sensors

## 1)Wiring up PX4
Wire the Pixhawk up as shown in the diagram. Refer to the [official guide](https://docs.px4.io/main/en/assembly/quick_start_pixhawk4)
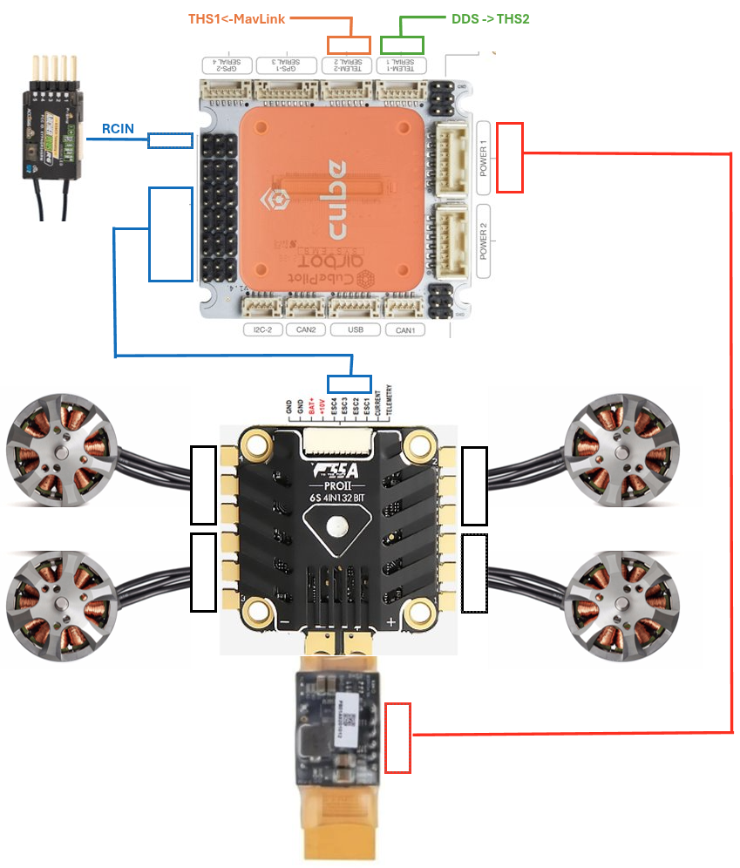
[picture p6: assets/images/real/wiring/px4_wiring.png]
px4 wiring


---

## 2) Connecting Px4
### PX4 Parameter setup

Flash the Pixhawk with the latest stable branch branch using QGroundControl. Branch `1.16.0` is tested.

List of all the updated parmeters
TODO

### Hardware wiring
The Px4 serial runs TTL level logic and the connecttech Hadron carier runs Rs-232 level logic. We need to use [RS-232 To TTL Conveter (MAX3232IDR)](https://www.seeedstudio.com/RS-232-To-TTL-Conveter-MAX3232IDR-p-2851.html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) to establish connection.

The wiring should look like below.

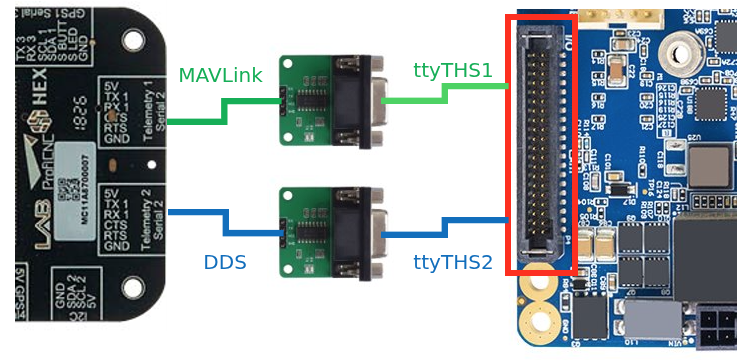
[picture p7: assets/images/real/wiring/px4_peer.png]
Px4 Wiring


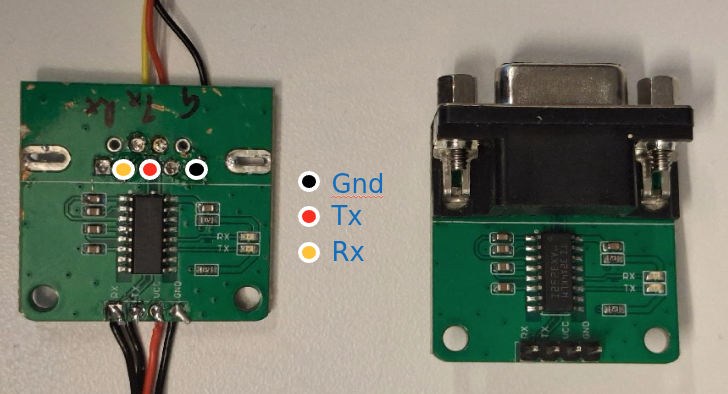
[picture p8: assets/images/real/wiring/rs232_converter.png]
Px4 Wiring


> **Note:** In each connection, wire TX -> RX and RX -> TX

## Flash PX4 with custom bootloader

### Install toolchain on host machine (Jetson)

```bash
# Linux packages
sudo apt install git make cmake python3-pip

# Python packages
pip install kconfiglib jinja2 empy jsonschema pyros-genmsg packaging toml numpy future

cd $HOME
git clone https://github.com/PX4/PX4-Autopilot.git -b v1.16.1 --recursive
cd PX4-Autopilot

# 1. Run the official PX4 Ubuntu setup script (it handles apt packages and toolchains)
cd ~/PX4-Autopilot
bash Tools/setup/ubuntu.sh

# 2. Restart your terminal session to apply the new path modifications
exec bash
```
### Build the firmware 

```bash
make cubepilot_cubeorangeplus_default
```

### Flash the firmware 

**Manual Flashing via GUI:** You want to generate the .px4 file on your machine but prefer to flash it manually using QGroundControl's custom firmware option

1. Generate firmware
```bash
make cubepilot_cubeorangeplus_default
```
2. Flash firmware using QGC
1. Open QGC 
2. Go to **Vehicle Setup** > **Firmware** > scroll to the bottom > click **Custom Firmware** 
3. Select the generated .px4 file from your build directory (e.g., ~/PX4-Autopilot/build/cubeorangeplus_default/px4_firmware/nuttx-px4fmu-v3.bin).
4. Start flashing
5. Follow the on-screen instructions to complete the update

**Auto upload:** You want to generate and upload the firmware directly from the terminal

```bash
make cubepilot_cubeorangeplus_default upload
```

### Verify connection
To verify hardware level connections use ```minicom```. Set (Using the QgrundControl Parameter editer) and change port number and baudrates accordingly.
```bash
minicom -D /dev/ttyTHS2 -b 921600 -o -8
```

#### MicroXRCE DDS Primary link -> THS2
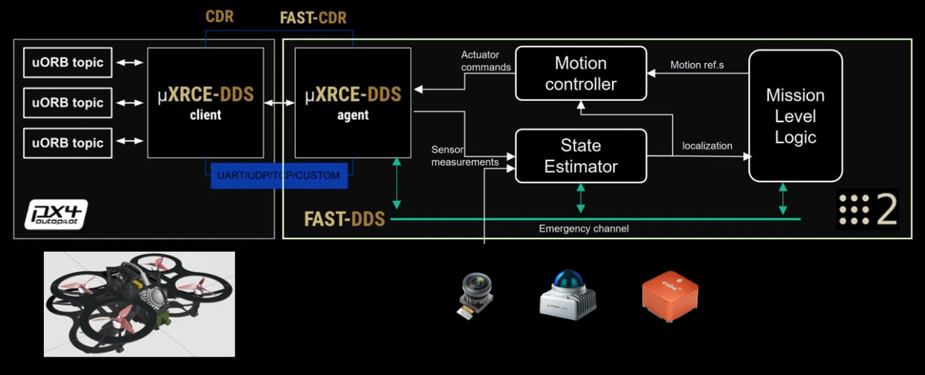
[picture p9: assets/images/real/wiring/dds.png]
dds

To verify primary control link to the Px4 Run this **AFTER** installing and launching ```agidocker```
```bash
agidocker
# *** Inside agidocker
cd /workspaces/dds
git clone -b v2.4.3 https://github.com/eProsima/Micro-XRCE-DDS-Agent.git
cd Micro-XRCE-DDS-Agent

```
According to the Fast RTPS documentation specify the ROS2 domain ID by adding the following to the participant profile into the `agent.refs`

```xml
<participant .....>
    <rtps>
        .....
        <builtin>
            <domainId>15</domainId>
        </buitin>
    </rtps>
</participan
```

```bash
# *** Inside agidocker
mkdir build
cd build
cmake ..
make
sudo make install
sudo ldconfig /usr/local/lib/
sudo MicroXRCEAgent serial --dev /dev/ttyTHS2 -b 921600
```
#### MavLink Secondary telemetry link -> THS1
This link is for routing the Mavlink Trafic to a Ground station in the local network or to internet

Install and follow [Mavlink Anywhere guide](https://github.com/alireza787b/mavlink-anywhere)
1. **Clone the repository:**
   ```sh
   # *** On the Host machine (not inside the container)
   cd ~/workspace/dds
   git clone https://github.com/alireza787b/mavlink-anywhere.git
   cd mavlink-anywhere
   ```
2. **Run the installation script:**
   ```sh
   chmod +x install_mavlink_router.sh
   sudo ./install_mavlink_router.sh
   ```

3. **Run the configuration script:**
   ```sh
   chmod +x configure_mavlink_router.sh
   sudo ./configure_mavlink_router.sh
   ```
2. **Follow the prompts to set up UART device, baud rate, and UDP endpoints:**
   - If an existing configuration is found, the script will use these values as defaults and show them to you
   - **UART Device**: Set this to `/dev/ttyTHS1`. This is the serial port connected to the mavlink of PX4.
   - **Baud Rate**: Default is `57600`. This is the communication speed between the companion computer and connected devices
   - **UDP Endpoints**: Input the ground station ip. Default is `0.0.0.0:14550`. You can enter multiple endpoints separated by spaces (e.g., `100.110.200.3:14550 100.110.220.4:14550`), `14550` is the default port QGC connets to.

2. **Connecting with QGroundControl**
Use QGroundControl to connect to your companion computer's IP address on the configured UDP endpoints. For internet-based telemetry, make sure to follow the setup video to properly register your devices on your chosen VPN system or configure port forwarding on your router.

- **Check the status of the service:**
  ```sh
  sudo systemctl status mavlink-router
  ```
- **View detailed logs:**
  ```sh
  sudo journalctl -u mavlink-router -f
  ```
- **Check uxrce_dds_client status**
go into the MAVLink consol of QGC and 
  ```sh
  nsh> uxrce_dds_client status
  INFO  [uxrce_dds_client] Running, connected
  INFO  [uxrce_dds_client] Using transport:     serial
  INFO  [uxrce_dds_client] Payload tx:          65072 B/s
  INFO  [uxrce_dds_client] Payload rx:          0 B/s
  INFO  [uxrce_dds_client] timesync converged: true
  uxrce_dds_client: cycle: 49416 events, 174925511us elapsed, 3539.86us avg, min 136us max 1013110us 12206.498us rms
  uxrce_dds_client: cycle interval: 49424 events, 21668.49us avg, min 137us max 890938308us 4007537.750us rms
  ```

> ***Troubleshoot*** : If `ros2 topic list`do not show the /fmu/.. topics, check if the domain id settings match between the **ROS2** in the docker, **uxrce_dds_client** and the **MicroXRCEAgent**
---

#### [Smart WiFi Manager Project](https://github.com/alireza787b/smart-wifi-manager)
Implement this if you need safe switiching between wifi APs
```bash
cd ~/workspace/dds
git clone https://github.com/alireza787b/smart-wifi-manager.git
cd smart-wifi-manager
sudo bash install.sh
sudo systemctl status smart-wifi-manager.service
sudo ./configure_smart_wifi_manager.sh
```

#### [NetBird VPN](https://netbird.io/)
NetBird can be used to 
- SSH to the drone over internet
- Forward data links like Mavlink telemetry over the internet
- Forward lightweight UI over the internet

```bash
curl -fsSL https://pkgs.netbird.io/install.sh | sh
netbird up 

# to add ssh keys to the remote host
ssh-copy-id sasa@<hostname>

# to reset key of ssh connections 
ssh-keygen -f "/home/sasa/.ssh/known_hosts" -R "<hostname>"

# Reconfigure mavlink router to add the GS ip over netbird
cd ~/workspace/dds/smart-wifi-manager
sudo ./configure_mavlink_router.sh
```

## 3) Interfacing and Verifying sensor connection

### Livox Lidar

#### Why [Mid 360](https://www.livoxtech.com/mid-360/specs). 
- 360 degree wide FOV
- Foarm Factor
- Active anti inference
- Const performace

Refer to the [Datasheets](../../assets/datasheets/Livox_Mid-360_User_Manual_EN.pdf) and [Wiki](https://livox-wiki-en.readthedocs.io/en/latest/)

#### Hardware connection

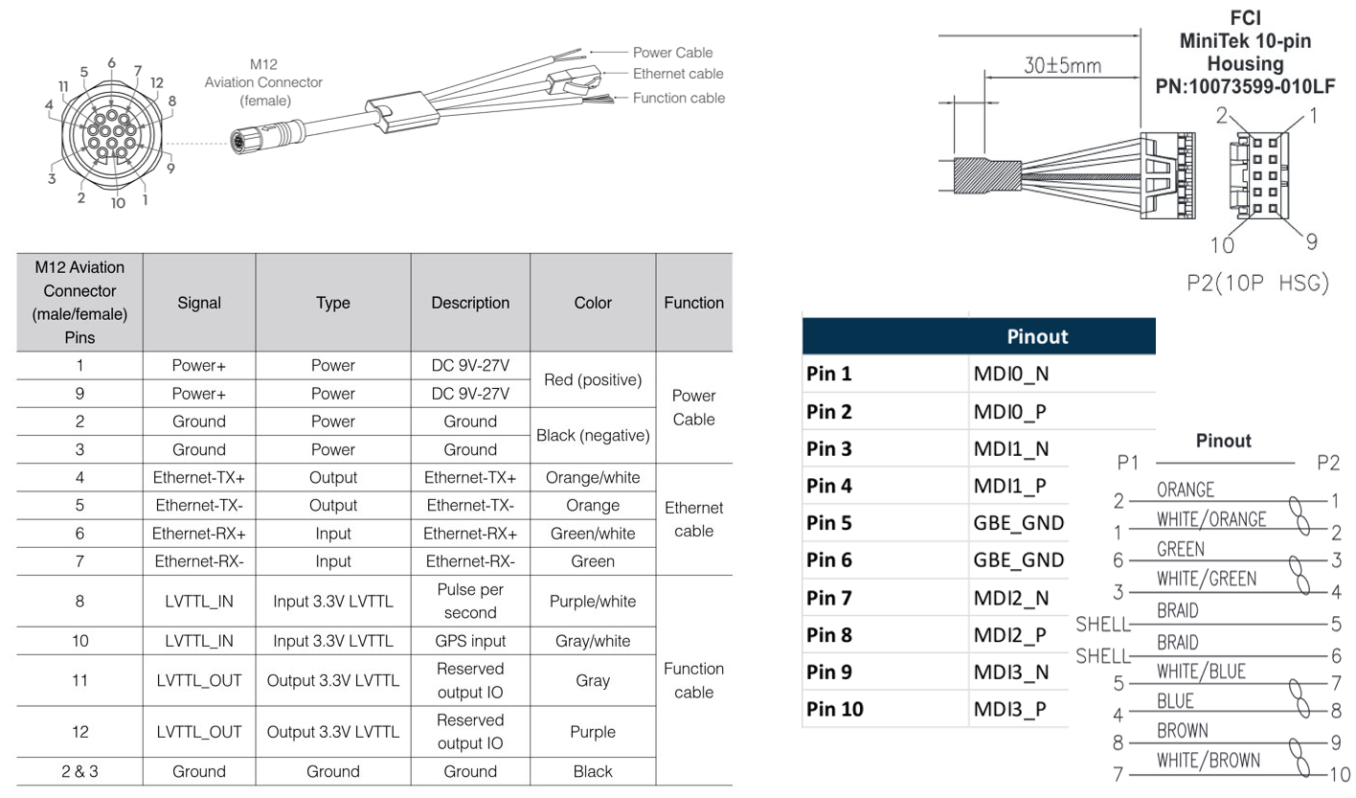
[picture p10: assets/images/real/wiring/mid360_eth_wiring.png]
Lidar Wiring


- The power can be supplied directly from the 6S battery with a 60V capacitor for safety
- The Original cable can be terminated to have only the required lenngth and connected with the Eth connector from the connecttech to save weight.
- THe sync wires should be kept in the processes for later step.

After the physical connection is made using the Lovix connecter to the Ethernet port of the Jetson a statis network has to be made with following command.

> **Note:** We advice [modifying the static IP](https://github.com/Livox-SDK/livox_ros_driver2/issues/135) of the Livox lidar from 192.168.1.1XX to 172.16.0.XX to avoid issues assessing the local(Wifi) network when connected.

Add the static wired connection using the GUI or CLI as follows, Following command assumes the ethernet interface is **enP8p1s0** and lidar ip is **172.16.0.50**.
```bash
sudo nmcli connection add type ethernet ifname enP8p1s0 con-name static-link ipv4.method manual ipv4.addresses 172.16.0.50/24 ipv4.gateway 172.16.0.1 ipv4.dns 8.8.8.8
sudo nmcli connection up static-link
```

After the hardware connection is made the [livox_viewer2](https://www.livoxtech.com/downloads) can be used to verify connection and **firmware Update**.
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

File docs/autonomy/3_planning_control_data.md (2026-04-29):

---
title: Autonomy-planning-control-datadriven
layout: doc
nav_title: Data driven Autonomy
wip: true
---
# Agipix Autonomy: Planning and Control
 



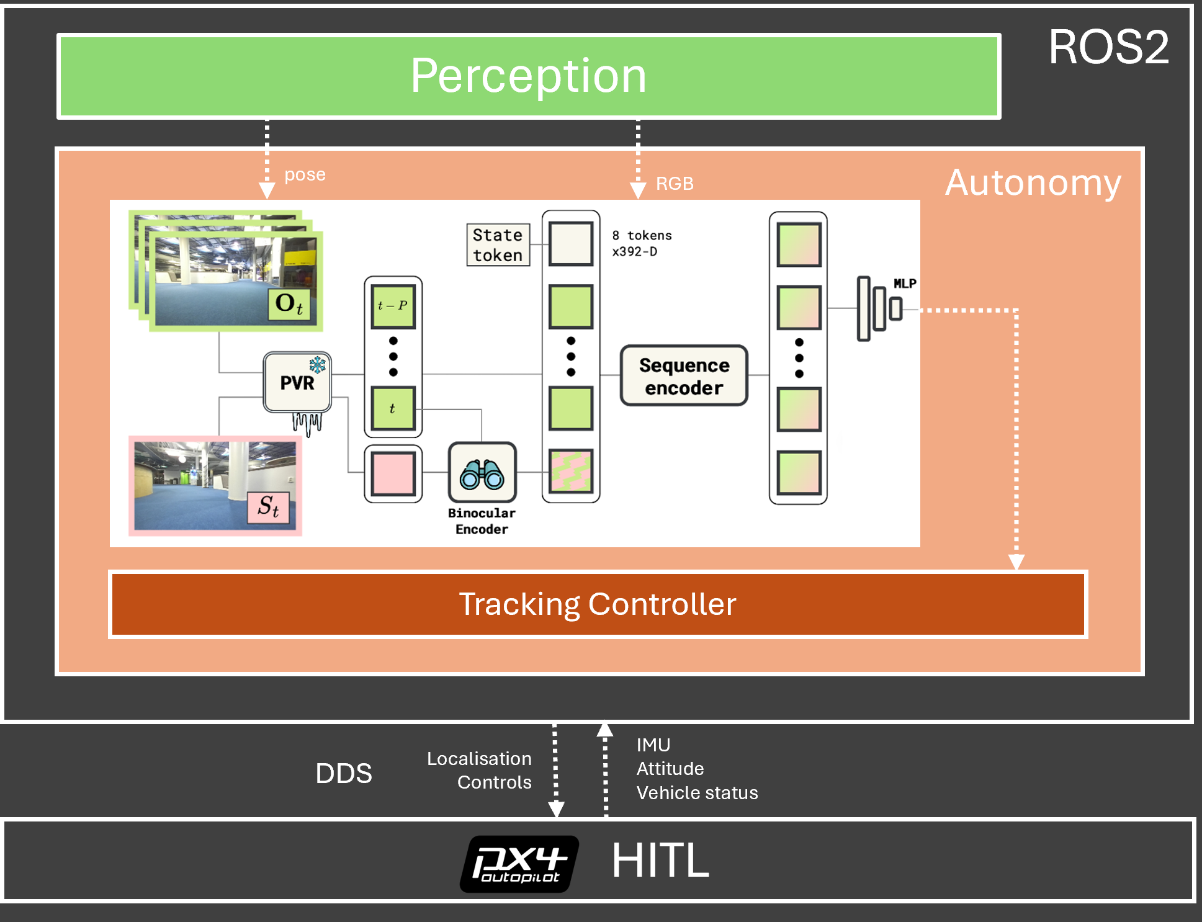
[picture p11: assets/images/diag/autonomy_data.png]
Autonomy overview

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

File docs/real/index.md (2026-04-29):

---
title: Overview
layout: doc
wip: true
---
# Agipix (Real Robot) — Quick Guide

Use this page to jump into the full real-platform bring-up flow, from mechanical assembly to preflight checks.

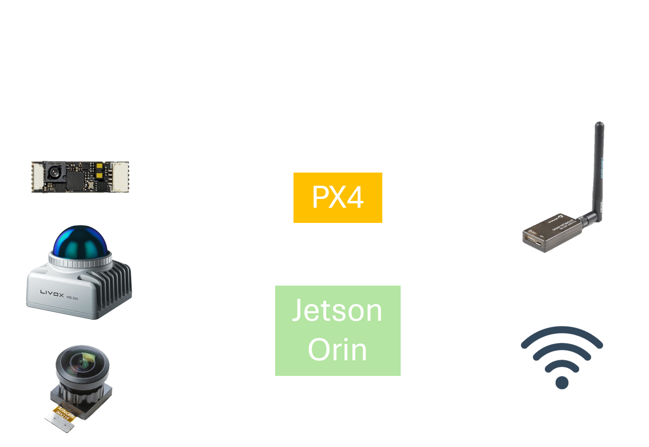
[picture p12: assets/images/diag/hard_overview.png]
HW overview

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

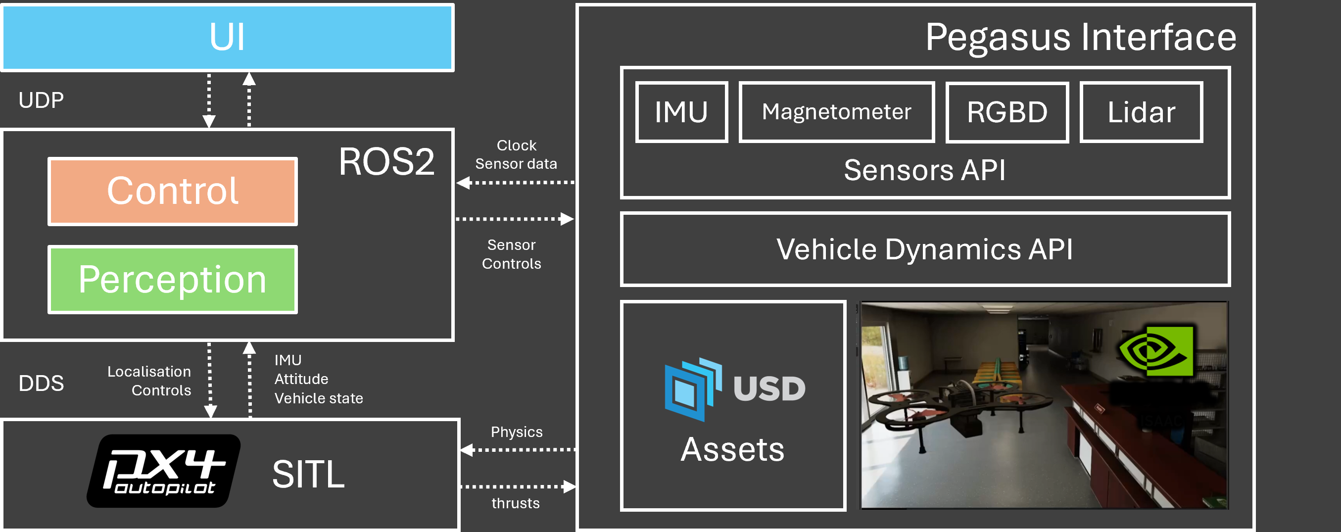
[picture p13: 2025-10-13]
assets/images/diag/sim_overview.png

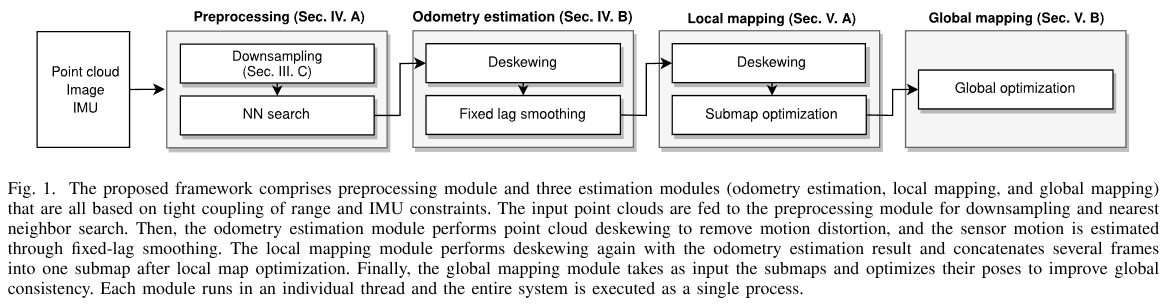
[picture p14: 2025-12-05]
assets/images/diag/perception_glim_overview.png

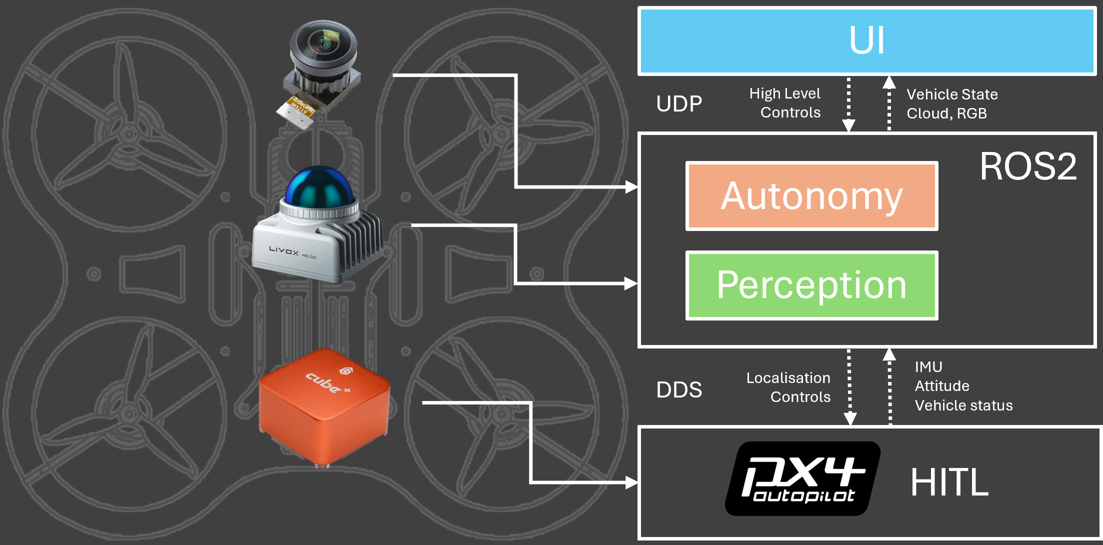
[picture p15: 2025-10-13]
assets/images/diag/auto_overview.png

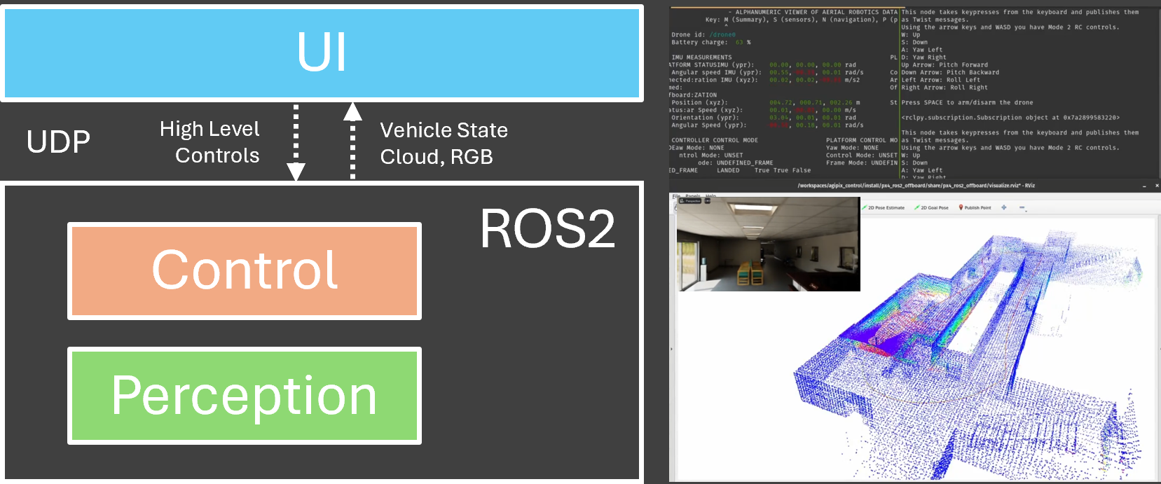
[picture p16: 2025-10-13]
assets/images/diag/ui_overview.png

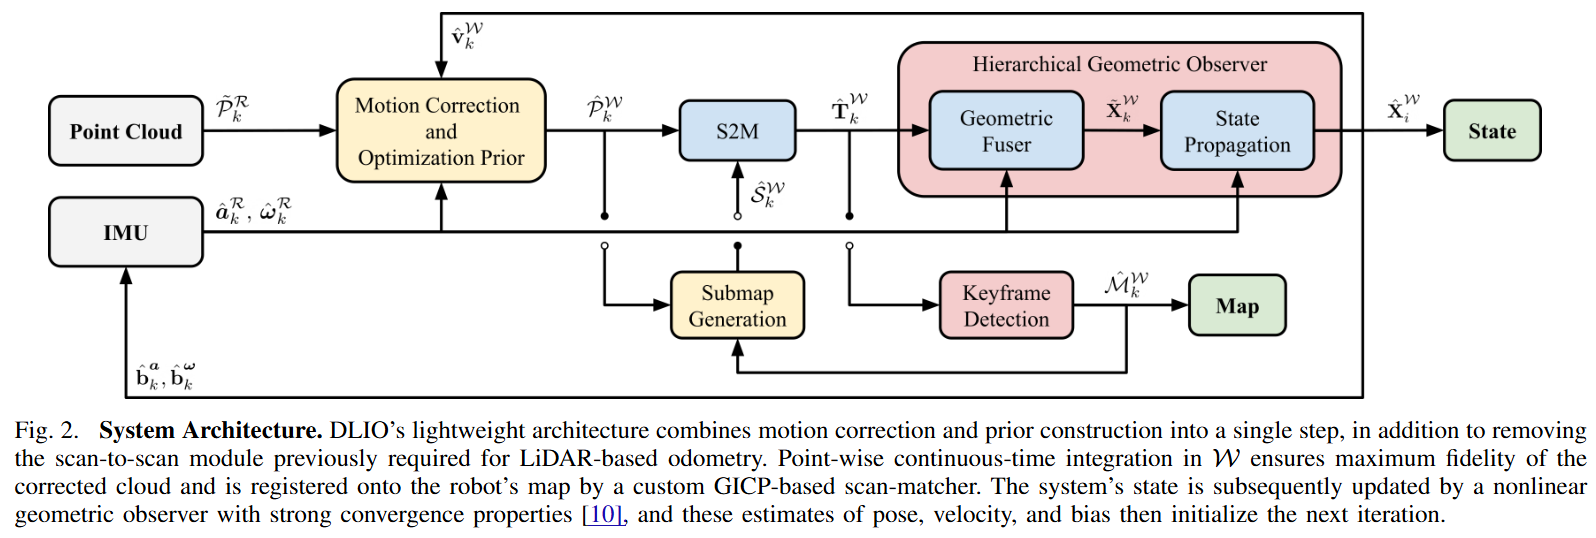
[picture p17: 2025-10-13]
assets/images/diag/perception_dlio_overview.png

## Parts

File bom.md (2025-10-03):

---
layout: doc
title: Bill of Materials
---

# Agipix Bill of Materials (BOM)

Quantities are per vehicle/unit unless noted otherwise.

## Components

| Item | Listing | Qty |
|---|---|---:|
| Main compute unit | Nvidia Jetson Orin NX | 1 |
| Breakout Board | ConnectTech HADRON ORIN NX | 1 |
| NX heatsink | NVIDIA JETSON ORIN NX/NANO ACTIVE HEATSINK (095-0181-000) | 1 |
| ESC | BF T-Motor F7 + F55A Pro II 3-6S 4-in-1 ESC | 1 |
| XT60 | Battery connector | 3 |
| Battery straps | Tekno RC Battery Straps (1x center, 1x side, EB/ET48 2.0) TKR9019 | 1 |
| Motors | T-Motor Slatts 2306.3 1700KV Motor (Pink) | 4 |
| Propeller | Azure Power SFP 5148 | 4 |
| Receiver | FrSky Archer Plus SR12+ | 1 |
| FC | CUBEPILOT | 1 |

## Sensors

| Item | Listing | Qty |
|---|---|---:|
| RGB Camera | Arducam 2MP Global Shutter OG02B10 Color Camera Modules Pivariety | 1 |
| RGBD camera | Intel realsense D455 | 1 |
| Lidar | Livox MID-360 | 1 |
| Optical flow | HereFlow Optic Flow Lidar Module for Ardupilot/PX4 | 1 |

## Miscellaneous

| Item | Listing | Qty |
|---|---|---:|
| Nut bolt set | Pulttisarja 330 kpl (philips-ruuvit, mutterit & aluslevyt) | 2 |
| Heat shrinks | VALUERC 280 PIECES COLORED HEAT SHRINK TUBE KIT (1/2/3/4/5/6/8/10MM) | 1 |
| Cable tie | DroneBuildr Zip tie / Cable tie (Pack of 20) | 2 |
| Mounting foam | 3M Double-Sided Mounting Foam | 2 |

---

**For complete BOM details**, visit [bom/BOM.md]({{ site.github.repository_url }}/blob/main/bom/BOM.md)

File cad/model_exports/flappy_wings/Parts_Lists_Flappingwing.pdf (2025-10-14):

Electronics and Processing

Component | Description
1 | Nano PI + STM32 | Central processor for signal processing
2 | DC Motor | For wing movement
3 | Servo Motor (x3) | 1 for claw, 2 for tail rudder & elevator
4 | IMU | Inertial Measurement Unit for position/orientation
5 | Infrared LED | Used as an active marker for OptiTrack indoor tracking
6 | Lithium Battery (4S) | Power source

Mechanical and Structural Components

Component | Description
1 | Carbon Fiber Tube | Lightweight tubing used for the main body structure
2 | 3D Printed Parts (PLA) | Small custom components used in structural assembly
3 | Carbon Fiber Rods | Serve as internal supports ("bones") for wing structure
4 | Ripstop/Nylon Fabric | Lightweight and durable material used as wing skin
5 | Spring used in Claw | Aluminum Used for grasping or interacting with objects
6 | Gears | Aluminum and 3D printed gears to reduce speed and increase torque from the actuator
7 | Hinge Mechanism | Enables joint movement; made of aluminum or 3D printed

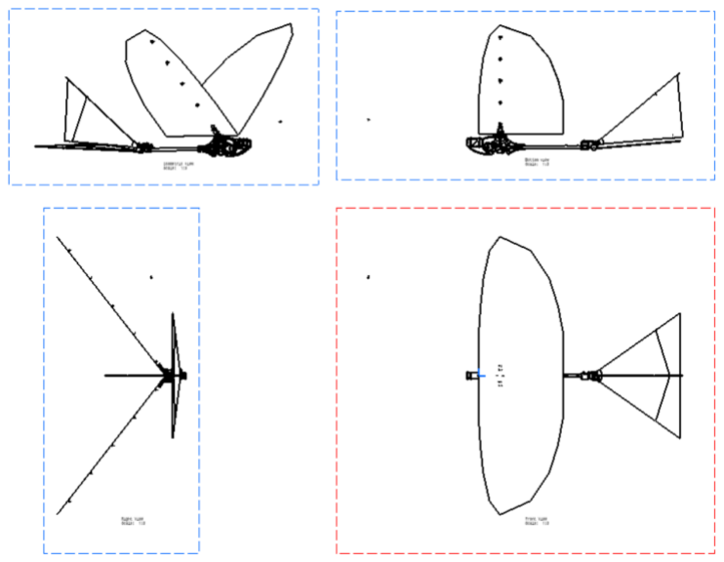
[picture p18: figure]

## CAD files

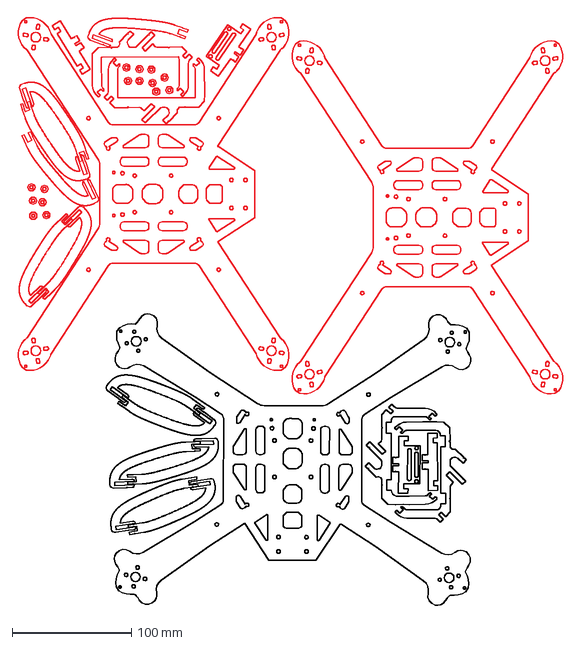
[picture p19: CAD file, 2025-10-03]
cad/Fab/CF/Whole_pattern_4mm_500x500.dxf
460.0 x 494.9 mm

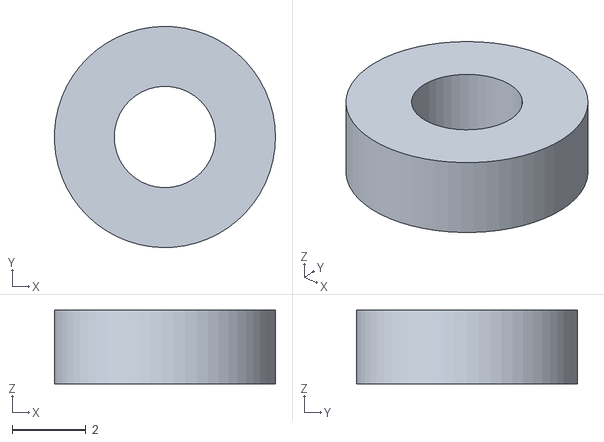
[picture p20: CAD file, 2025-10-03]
cad/Fab/3D_prints/battery_bush_x2.stl
6.00 x 6.00 x 2.00

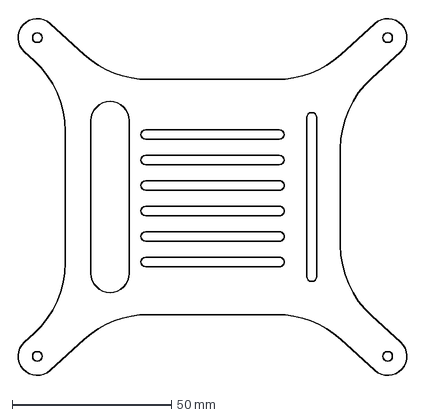
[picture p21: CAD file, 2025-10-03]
cad/Fab/CF/1.5mm/top_grd.dxf
123.3 x 113.3 mm

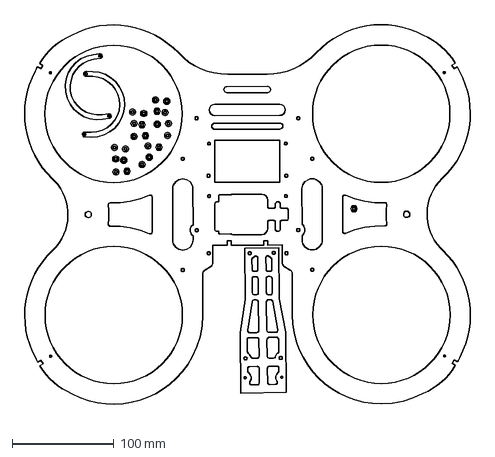
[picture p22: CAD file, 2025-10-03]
cad/Fab/CF/1_5mm_500x600_1.dxf
454.9 x 393.7 mm

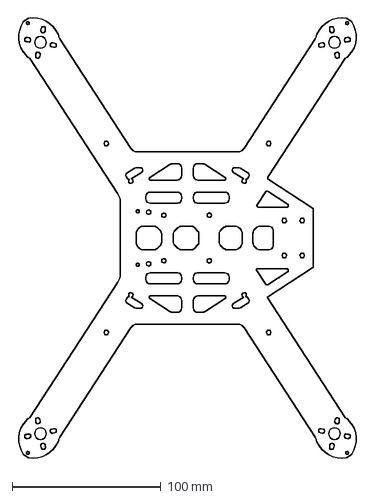
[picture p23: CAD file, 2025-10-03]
cad/Fab/CF/4mm/base.dxf
230.4 x 298.6 mm

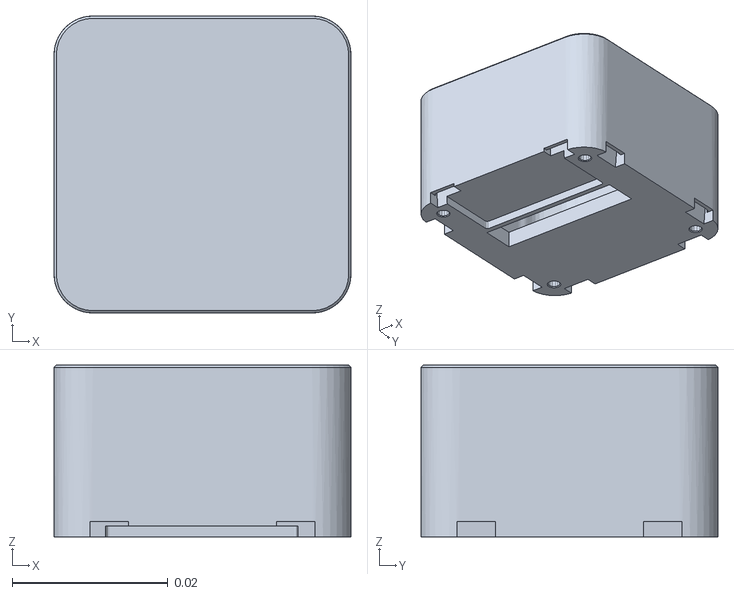
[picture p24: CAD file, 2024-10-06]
cad/model_exports/agipix/cube_orange.stl
0.0382 x 0.0382 x 0.0221

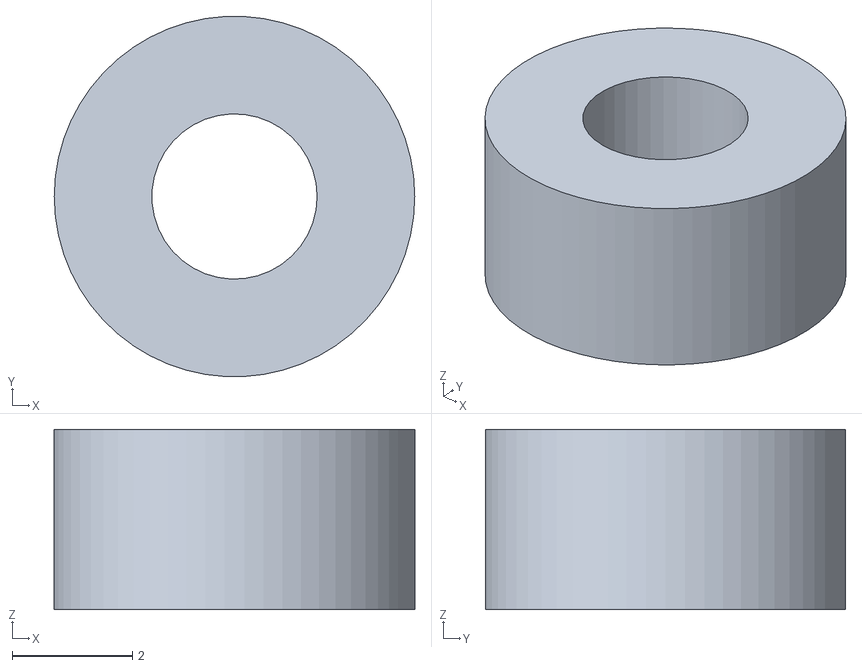
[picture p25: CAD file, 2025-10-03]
cad/Fab/3D_prints/front_cam_bush_x2.stl
6.00 x 5.99 x 3.00

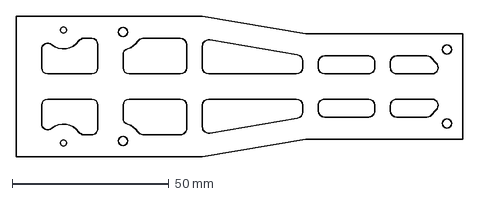
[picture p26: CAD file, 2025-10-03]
cad/Fab/CF/1.5mm/bat_plate.dxf
142.3 x 44.7 mm

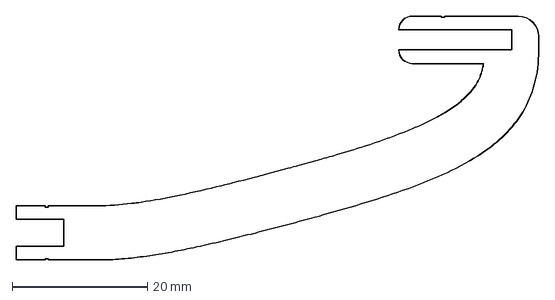
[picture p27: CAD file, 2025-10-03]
cad/Fab/CF/4mm/prop_grd_x4.dxf
77.1 x 36.0 mm

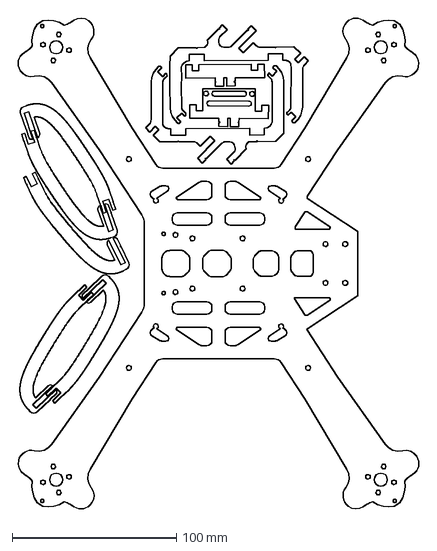
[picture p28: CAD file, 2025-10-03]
cad/Fab/CF/mod_4mm_500x500.dxf
246.1 x 300.9 mm

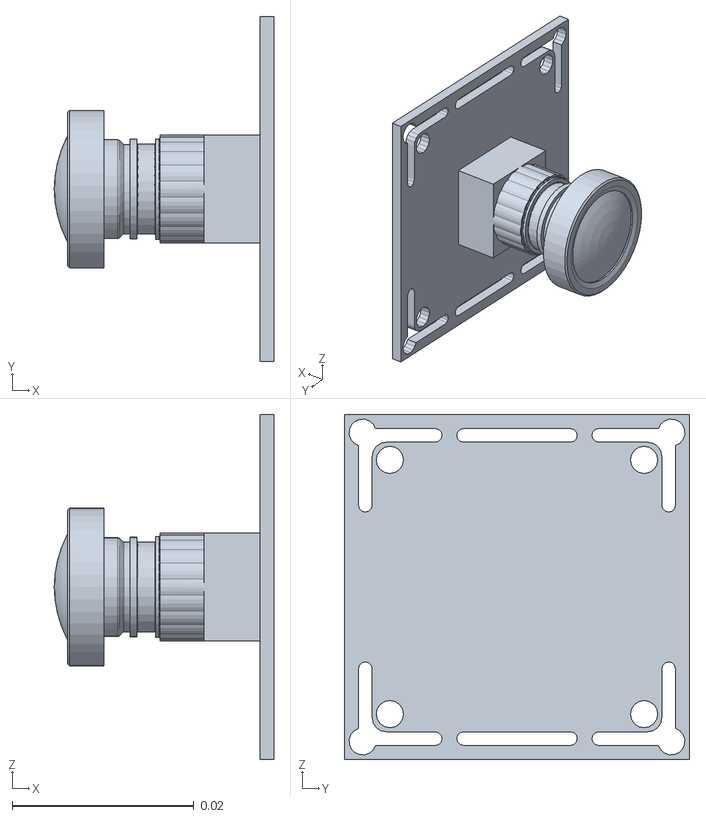
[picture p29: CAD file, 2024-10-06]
cad/model_exports/agipix/camera.stl
0.0242 x 0.038 x 0.038

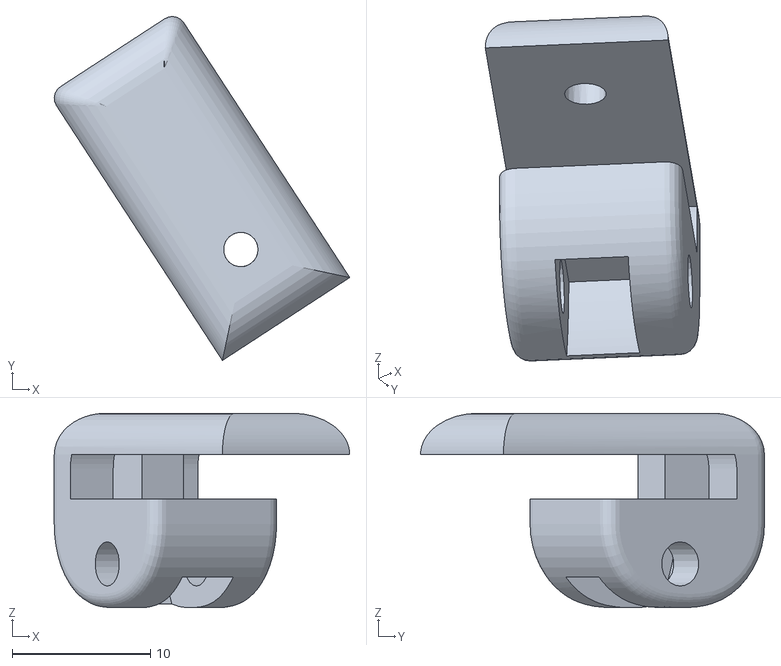
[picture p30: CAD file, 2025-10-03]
cad/Fab/3D_prints/side_joint_upper.stl
21.4 x 24.9 x 14.1

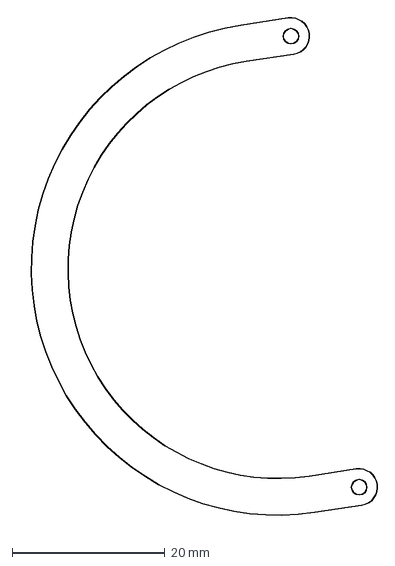
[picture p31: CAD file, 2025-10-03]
cad/Fab/CF/1.5mm/cage_top.dxf
47.4 x 66.6 mm

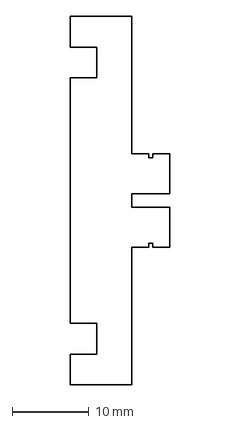
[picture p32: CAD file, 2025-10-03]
cad/Fab/CF/4mm/cage_mid.dxf
13.0 x 48.0 mm

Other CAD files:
cad/Fab/Al_fab/landing_gear.dwg
cad/Fab/CF/V2_4mm_500_lidar_1.dxf
cad/model_exports/agipix/lidar.stl
cad/Fab/3D_prints/D455_rubber_mount_R.stl
cad/Fab/3D_prints/D455_rubber_mount_Ll.stl
cad/Fab/3D_prints/F55A_bush_adaptor.stl
cad/Fab/3D_prints/F55A_bush_adaptor_in.stl
cad/Fab/3D_prints/flow_ext_pole.stl
cad/Fab/3D_prints/front_left_x2.stl
cad/Fab/3D_prints/front_right_x2.stl
cad/Fab/3D_prints/landing damper.stl
cad/Fab/3D_prints/landing_gear_bush.stl
cad/Fab/3D_prints/nx_bush_x4.stl
cad/Fab/3D_prints/px4_pad.stl
cad/Fab/3D_prints/side_joint_lower.stl
cad/Fab/3D_prints/top_gurd_flexies_x4.stl
cad/Fab/Al_fab/OldVersions/landing_gear.0001.dwg
cad/Fab/Al_fab/landing_gear.ipt
cad/Fab/CF/1.5mm/top_plate_x2.dxf
cad/Fab/CF/1_5mm_500x600.dxf
cad/Fab/CF/4mm/bush.dxf
cad/Fab/CF/4mm/cage_bot_x2.dxf
cad/Fab/CF/4mm/cage_mid_f.dxf
cad/Fab/CF/4mm_500x500.dxf
cad/Fab/CF/EDITED_new_cut_4mm_500x500.dxf
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

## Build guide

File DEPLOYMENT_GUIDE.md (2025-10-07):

# Agipix GitHub Pages - Quick Start Guide

## 🎨 What Was Built

A **dark-themed, futuristic website** for the Agipix project featuring:

### Design Elements
- 🌑 **Dark Theme**: Black (#0a0a0a) background with dark red (#8b1a1a, #b32424) accents
- ✨ **Glowing Header**: "AGIPIX" in Orbitron font with animated red glow effect
- 🤖 **Digital Twin Focus**: Split sim/real sections emphasizing seamless deployability
- 📱 **Fully Responsive**: Adapts to mobile, tablet, and desktop screens

### Pages Created
1. **Homepage** (`index.html`)
   - Hero section with exploded.gif banner
   - Sim-to-Real split comparison
   - 6 key highlights in grid layout
   - Quick start guide with 3 categories
   - Repository layout reference

2. **Documentation Pages** (`docs/`)
   - Simulation Setup
   - Hardware Assembly
   - Flashing Hardware
   - Software Setup
   - Autonomy Framework

3. **Bill of Materials** (`bom.md`)
   - Complete component list
   - Sensor specifications
   - Miscellaneous items

### Navigation
- Sticky header with "AGIPIX" title (glowing on hover)
- Clean nav bar: Home | Sim Setup | Hardware | Autonomy | BOM | GitHub
- Footer with contact info and acknowledgments

## 🚀 How to Deploy

### Step 1: Enable GitHub Pages
1. Go to your repository: `https://github.com/SasaKuruppuarachchi/agipix`
2. Click **Settings** tab
3. Scroll to **Pages** section (left sidebar)
4. Under **Source**:
   - Branch: Select `main` (or the branch with these changes)
   - Folder: Select `/ (root)`
5. Click **Save**

### Step 2: Wait for Build
- GitHub Actions will automatically build the site
- Check the **Actions** tab to monitor progress
- Build usually completes in 1-2 minutes

### Step 3: Visit Your Site
- URL: `https://sasakuruppuarachchi.github.io/agipix/`
- The site will be live once the build completes!

## 📁 Files Added

```
agipix/
├── _config.yml                    # Jekyll configuration
├── _layouts/
│   ├── default.html              # Main layout (header, nav, footer)
│   └── doc.html                  # Documentation page layout
├── assets/css/
│   └── style.scss                # Dark theme CSS (10KB)
├── index.html                     # Homepage
├── docs/                          # Documentation pages
│   ├── sim-setup.md
│   ├── hardware-assembly.md
│   ├── flashing-hardware.md
│   ├── software-setup.md
│   └── autonomy.md
├── bom.md                         # Bill of Materials
├── Gemfile                        # Ruby dependencies
├── GITHUB_PAGES_README.md         # Detailed setup guide
└── SITE_SUMMARY.md               # Implementation details
```

## 🎯 Key Features

### Homepage Highlights
1. **Sim-to-Real Deployability** - Zero code changes between environments
2. **Open-Source Platform** - Full BOM, CAD, and software stack
3. **Modular Autonomy Stack** - ROS 2-based decoupled architecture
4. **Small Form Factor** - 438×372 mm with TWR ≈ 2.98:1
5. **Extensive Sensor Suite** - 3D LiDAR, RGB camera, IMU
6. **Modular Hardware Design** - Layered decks for easy upgrades

### Visual Design
- **Color Scheme**:
  - Background: `#0a0a0a` (deep black)
  - Accents: `#8b1a1a` (dark red), `#b32424` (bright red)
  - Text: `#e0e0e0` (light gray), `#a0a0a0` (medium gray)

- **Typography**:
  - Headers: Orbitron (Google Fonts) - futuristic, tech-inspired
  - Body: System fonts for performance

- **Effects**:
  - Glowing text on header
  - Hover animations on cards and buttons
  - Smooth transitions (0.3s ease)
  - Custom dark scrollbar

### Content Integration
- Documentation pulls from `doc/` directory
- Images load from `assets/images/`
- Links to original repository docs for complete info
- Automatic markdown rendering

## 🔧 Local Development

### Prerequisites
```bash
# Install Ruby and Jekyll
gem install --user-install bundler jekyll
```

### Build & Preview
```bash
# Navigate to repository
cd /path/to/agipix

# Build the site
export PATH="$HOME/.local/share/gem/ruby/3.2.0/bin:$PATH"
jekyll build

# Serve locally
jekyll serve --baseurl /agipix

# Open browser
# http://localhost:4000/agipix/
```

## 📝 Customization

### Change Colors
Edit `assets/css/style.scss`:
```scss
:root {
  --accent-red: #8b1a1a;          /* Change this */
  --accent-red-light: #b32424;    /* And this */
}
```

### Update Content
- Homepage: Edit `index.html`
- Documentation: Edit files in `docs/`
- Navigation: Edit `_layouts/default.html`

### Add New Pages
1. Create new `.md` or `.html` file
2. Add front matter:
   ```yaml
   ---
   layout: doc
   title: Your Title
   ---
   ```
3. Add link to navigation in `_layouts/default.html`

## ✅ Verification Checklist

- [x] Jekyll site builds without errors
- [x] Dark theme with red accents renders correctly
- [x] Orbitron font loads for "AGIPIX" header
- [x] All navigation links work
- [x] Images load from assets/images/
- [x] Documentation pages render properly
- [x] Responsive design works on mobile
- [x] Footer displays contact info
- [x] Code blocks are syntax highlighted

## 🎬 Next Steps

1. **Merge this PR** to include the GitHub Pages files
2. **Enable GitHub Pages** in repository settings
3. **Share the URL**: `https://sasakuruppuarachchi.github.io/agipix/`
4. **Optional**: Set up custom domain in Settings → Pages

## 📚 Documentation

- **GITHUB_PAGES_README.md** - Complete setup and customization guide
- **SITE_SUMMARY.md** - Detailed implementation documentation
- **This file** - Quick start guide

## 🎨 Screenshots

The site features:
- Dark, futuristic homepage with animated header
- Split sim/real comparison sections
- Clean documentation pages with code highlighting
- Professional footer with project information

## 🆘 Troubleshooting

### Site not building?
- Check Actions tab for build errors
- Ensure branch is selected in Pages settings
- Verify _config.yml is valid YAML

### Images not showing?
- Confirm images exist in `assets/images/`
- Check that baseurl is set to `/agipix`
- Images should use relative paths

### Local preview not working?
```bash
# Clear cache and rebuild
jekyll clean
jekyll build --baseurl /agipix
jekyll serve --baseurl /agipix
```

## 📧 Support

For issues or questions:
- Sasanka Kuruppu Arachchige: sasa.kuruppuarachchi@gmail.com
- Joni Kämäräinen: joni.kamarainen@tuni.fi

---

**The Agipix GitHub Pages site is ready to deploy! 🚀**

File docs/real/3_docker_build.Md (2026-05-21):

---
title: Building Containerised Development platform
layout: doc
nav_title: Docker Build
---

# Building Containerised Development platform

The containerised development platform is shared by both sim and real hardware. This improve the deployability from sim to real with minimal code change.
> Curent release uses [Nvidia Isaac Ros 3.2](https://github.com/NVIDIA-ISAAC-ROS/isaac_ros_common/tree/release-3.2) as the basis for this platform

### Prerequisities
- Finish Flasing Hadrware or setting up Sim host.

## 1) Install Docker + NVIDIA Container Toolkit + Git LFS
Install docker with
- Guide from [JetsonHacks](https://jetsonhacks.com/2025/02/24/docker-setup-on-jetpack-6-jetson-orin/)
```bash
cd hacks
git clone https://github.com/jetsonhacks/install-docker.git
cd install-docker
bash ./install_nvidia_docker.sh
bash ./configure_nvidia_docker.sh
```

Or use
- Docker: https://docs.docker.com/engine/install/ubuntu/
- NVIDIA Container Toolkit: https://docs.nvidia.com/datacenter/cloud-native/container-toolkit/latest/install-guide.html

Git LFS: https://git-lfs.com/
```bash
curl -s https://packagecloud.io/install/repositories/github/git-lfs/script.deb.sh | sudo bash
# Install Git LFS
sudo apt update
sudo apt install git-lfs -y

# Initialize Git LFS for your user
git lfs install

```

To verify CDI interfaces `sudo nvidia-ctk cdi list` should output
```bash
INFO[0000] Found 2 CDI devices                          
nvidia.com/pva=0
nvidia.com/pva=all
```
> if no CDI devices are found
```bash
sudo apt-get install -y nvidia-container-toolkit
sudo systemctl restart docker
```

## 2) Setup Workspace

```bash
cd $HOME
mkdir workspace && cd workspace
mkdir -p agipix_control/src dds lidar_ws/src raicam-ros/src logging/src logging/bags logging/flogs logging/crashreports
cd raicam-ros/src
git clone https://github.com/SasaKuruppuarachchi/isaac_ros_common.git # TODO

echo "export WORKSPACES_DIR="$HOME/workspace"" >> ~/.bashrc
echo "export ISAAC_ROS_DEV_DIR="$HOME/workspace/raicam-ros"" >> ~/.bashrc
echo "alias agidocker='cd $HOME/workspace/raicam-ros/src/isaac_ros_common/scripts/ && ./run_dev.sh --skip-registry-check'" >> ~/.bashrc
echo "alias killagidocker='docker container kill isaac_ros_dev-aarch64-container'" >> ~/.bashrc
source ~/.bashrc
```
## 3) Build Docker

In this step we pull source images and build the docker continer.
To customise the docker configuration edit 
```bash
code ~/workspace/raicam-ros/src/isaac_ros_common/scripts/.isaac_ros_common-config
# append the additional docker configuration layers you need built

cd ~/workspace/raicam-ros/src/isaac_ros_common/scripts/ && ./run_dev.sh # this alias builds the container
```
The build will take more than an hour and if successfull you will see ```Running isaac_ros_dev-aarch64-container``` and the container will start running in the background.

Run ```agidocker``` to attach to the container interactively.

Verify Pytorch with cuda on dcker
```bash
agidocker
# Inside docker
python3 - << 'EOF'
import torch
print("CUDA:", torch.cuda.is_available())
print("Device:", torch.cuda.get_device_name(0))
EOF

```

## 4) Post setup (Optional)

### Build Opencv with cuda From source
> Note! OpenCV =< 4.8 had an incompatability with Cuda 12.x
```bash
agidocker
# Inside docker
cd /worckspaces/isaac_ros-dev/src/isaac_ros_common
sudo ./build_ocv_cuda.sh
# This will build and install the OCV for this running container locally 
# but saves the build files on the mounted folder so we can use the Dockerfile.opencv layer later
```

### Build torchvision from source (matches NVIDIA PyTorch)
```bash
export FORCE_CUDA=1
git clone -b v0.17.2 https://github.com/pytorch/vision.git
cd vision
sudo -E python setup.py develop  # use 'install' if you don't need editable mode
```

## 5) Prune Docker cash (Optional)

Docker builder cash consumes lot of memory. You can clean manualy or schedule a clean as follows
```bash
docker system prune -a --volumes
```
Output will show the size of the volume freed up `Total reclaimed space: 60.52GB`

Optional **not recommended**: Prevent buildup with a scheduled cleanup (e.g., every week):
```bash
docker system prune -a --filter "until=168h" --volumes

sudo du -h --max-depth=1 /home/<user>/workspace | sort -hr

rm -rf ~/.cache/*

rm -rf ~/.local/share/Trash/*
rm -rf ~/.local/share/pip
rm -rf ~/.local/share/virtualenvs

```

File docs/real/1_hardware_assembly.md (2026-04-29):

---
title: Hardware Assembly
layout: doc
wip: true
---

# Complete Guide for Building the Agipix Hardware Platform

## Material checklist

 [Bill of Materials (BOM)](https://sasakuruppuarachchi.github.io/agipix/bom.html)

## Carbon fibre cuts

Use the supplied cutting patterns available at cad/Fab/CF and use a water-jet cutting method to cut.

| File name | Material |
|---|---|
| tocut_1_5mm_500x600.dxf | 500x600x1.5mm |
| tocut_1_5mm_500x600.dxf | 500x600x1.5mm |
| tocut_4mm_500x500.dxf | 500x500x4.0mm |

### Postprocessing of parts
Some CF parts need extra processing to support lataral fitting.

> **Note:** TODO: Detailed description with images

## 3D printed parts

Use the supplied 3D printable stl files available at cad/Fab/3D_prints and use followig settings to print them

- Filament: AmazonBasics TPU (preferred for durability);
- Nozzle: 0.4 mm 
- Layer height: 0.2 mm
- Infill: 40% gyroid/cubic; 70% for bushings/adaptors
- Temperatures: TPU 235–245°C nozzle

- Post-processing: deburr, ream holes, clean support interfaces

| File name | Quantity |
|---|---|
| battery_bush_x2.stl | 2 |
| D455_rubber_mount_Ll.stl | 1 |
| D455_rubber_mount_R.stl | 1 |
| F55A_bush_adaptor_in.stl | 1 |
| F55A_bush_adaptor.stl | 1 |
| front_cam_bush_x2.stl | 2 |
| front_left_x2.stl | 2 |
| front_right_x2.stl | 2 |
| landing damper.stl | 1 |
| landing_gear_bush.stl | 1 |
| nx_bush_x4.stl | 4 |
| px4_pad.stl | 1 |
| side_joint_lower.stl | 1 |
| side_joint_upper.stl | 1 |
| top_gurd_flexies_x4.stl | 1 |

parts

## Assembly

### Low level assembly and test

In this step we setup following componenets before the low level test
- Frame
- Power, Bttery
- ESC
- Motors
- Radio reciever
- Telemetry radio
- Flight Controller

Finally we do a seris of manual flight tests to verify

> **Note:** TODO: Detailed steps with images

### High level Assembly

In this step we setup following componenets before attempting high level controls
- Top plate
- USB to TTL or RS323-USB converter
- Jetson Orin NX with Hadron carrier
- Wifi antenna
- Wiring and Complient frame stiffner 

> **Note:** TODO: Detailed steps with images

Now we are ready to Firmware setup. See [Instructions](./2_flashing_hardware.md) to continue.

### Sensor Assembly

In this step we setup following componenets before attempting high level controls
- Carbon Fibre Sensor Cage
- Livox Mid-360 Lidar
- (Optional) RGB camera
- (Optional) RGBD camera

> **Note:** TODO: Detailed steps with images

### High level Assembly

In this step we setup following componenets before attempting high level controls
- Top plate
- USB to TTL or RS323-USB converter
- Jetson Orin NX with Hadron carrier
- Wifi antenna
- Wiring

> **Note:** TODO: Detailed steps with images

Now we are ready for software setup. See [Instructions](./3_software_setup.md) to continue.

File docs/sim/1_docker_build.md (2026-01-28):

---
title: Host setup
layout: doc
---
# Setting Up the Agipix Simulation Environment

### Prerequisites for host PC
- Ubuntu 20.04/22.04 Operating System
- NVIDIA GPU (RTX 2070 or higher)
- NVIDIA GPU Driver (recommended version 525.85)

### Cuda and CUDnn
> !! Importat: Always use the given liks to get the latest deb package links wt is statud here may be outdated.

Install cuda with the instructions [here](https://developer.nvidia.com/cuda-12-8-0-download-archive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)
```bash
wget https://developer.download.nvidia.com/compute/cuda/repos/ubuntu2204/x86_64/cuda-ubuntu2204.pin
sudo mv cuda-ubuntu2204.pin /etc/apt/preferences.d/cuda-repository-pin-600
wget https://developer.download.nvidia.com/compute/cuda/12.8.0/local_installers/cuda-repo-ubuntu2204-12-8-local_12.8.0-570.86.10-1_amd64.deb
sudo dpkg -i cuda-repo-ubuntu2204-12-8-local_12.8.0-570.86.10-1_amd64.deb
sudo cp /var/cuda-repo-ubuntu2204-12-8-local/cuda-*-keyring.gpg /usr/share/keyrings/
sudo apt-get update
sudo apt-get -y install cuda-toolkit-12-8
```

Install Cudnn with the instructions [here](https://developer.nvidia.com/cudnn-downloads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)
```bash
wget https://developer.download.nvidia.com/compute/cudnn/9.18.1/local_installers/cudnn-local-repo-ubuntu2204-9.18.1_1.0-1_amd64.deb
sudo dpkg -i cudnn-local-repo-ubuntu2204-9.18.1_1.0-1_amd64.deb
sudo cp /var/cudnn-local-repo-ubuntu2204-9.18.1/cudnn-*-keyring.gpg /usr/share/keyrings/
sudo apt-get update
sudo apt-get -y install cudnn

echo 'export PATH=/usr/local/cuda-12.8/bin:$PATH' >> ~/.bashrc
echo 'export LD_LIBRARY_PATH=/usr/local/cuda-12.8/lib64:$LD_LIBRARY_PATH' >> ~/.bashrc
```

Verify
```bash
nvcc -V
cd $HOME/workspace/raicam-ros/src/isaac_ros_common/verify
g++ verify_cuda_cudnn.cpp \
    -I/usr/local/cuda-12.8/targets/x86_64-linux/include \
    -L/usr/local/cuda-12.8/targets/x86_64-linux/lib \
    -lcudart -lcudnn -o verify_cuda_cudnn
./verify_cuda_cudnn
```

# Building Containerised Development platform

The containerised development platform is shared by both sim and real hardware. This improve the deployability from sim to real with minimal code change.
> Curent release uses [Nvidia Isaac Ros 3.2](https://github.com/NVIDIA-ISAAC-ROS/isaac_ros_common/tree/release-3.2) as the basis for this platform

### Prerequisities
- Finish Flasing Hadrware or setting up Sim host.

## 1) Install Docker + NVIDIA Container Toolkit + Git LFS
Install docker with
- Guide from [JetsonHacks](https://jetsonhacks.com/2025/02/24/docker-setup-on-jetpack-6-jetson-orin/)
```bash
cd hacks
git clone https://github.com/jetsonhacks/install-docker.git
cd install-docker
bash ./install_nvidia_docker.sh
bash ./configure_nvidia_docker.sh
```

Or use
- Docker: https://docs.docker.com/engine/install/ubuntu/
- NVIDIA Container Toolkit: https://docs.nvidia.com/datacenter/cloud-native/container-toolkit/latest/install-guide.html

Git LFS: https://git-lfs.com/
```bash
curl -s https://packagecloud.io/install/repositories/github/git-lfs/script.deb.sh | sudo bash
# Install Git LFS
sudo apt update
sudo apt install git-lfs -y

# Initialize Git LFS for your user
git lfs install

```

To verify CDI interfaces `sudo nvidia-ctk cdi list` should output
```bash
INFO[0000] Found 2 CDI devices                          
nvidia.com/pva=0
nvidia.com/pva=all
```
> if no CDI devices are found
```bash
sudo apt-get install -y nvidia-container-toolkit
sudo systemctl restart docker
```

## 2) Setup Workspace

```bash
cd $HOME
mkdir workspace && cd workspace
mkdir -p agipix_control/src dds lidar_ws/src raicam-ros/src ui/src logging/bags logging/flogs logging/crashreports
cd raicam-ros/src
git clone https://github.com/SasaKuruppuarachchi/isaac_ros_common.git # TODO

echo "export WORKSPACES_DIR="$HOME/workspace"" >> ~/.bashrc
echo "export ISAAC_ROS_DEV_DIR="$HOME/workspace/raicam-ros"" >> ~/.bashrc
echo "alias agidocker='cd $HOME/workspace/raicam-ros/src/isaac_ros_common/scripts/ && ./run_dev.sh --skip-registry-check'" >> ~/.bashrc
echo "alias killagidocker='docker container kill isaac_ros_dev-x86_64-container'" >> ~/.bashrc
source ~/.bashrc
```
## 3) Build Docker

In this step we pull source images and build the docker continer.
- To customise the docker configuration edit and append the additional docker configuration layers you need built
    ```bash
    code ~/workspace/raicam-ros/src/isaac_ros_common/scripts/.isaac_ros_common-config
    ```

- Change the ROS_DOMAIN_ID to 3 (To mactch the sim environment)
    ```bash
    code ~/workspace/raicam-ros/src/isaac_ros_common/scripts/bashrc
    ```

Build the Docker    

```bash
cd ~/workspace/raicam-ros/src/isaac_ros_common/scripts/ && ./run_dev.sh # this alias builds the container
```
The build will take more than an hour and if successfull you will see ```Running isaac_ros_dev-aarch64-container``` and the container will start running in the background.

Run ```agidocker``` to attach to the container interactively.

Verify Pytorch with cuda on dcker
```bash
agidocker
# Inside docker
python3 - << 'EOF'
import torch
print("CUDA:", torch.cuda.is_available())
print("Device:", torch.cuda.get_device_name(0))
EOF

```

### (Optional) Installing Portainer CE
&emsp; Portainer CE is an open-source GUI for creating and managing docker containers. Install it following [these instructions](https://docs.portainer.io/start/install-ce/server/docker/linux)

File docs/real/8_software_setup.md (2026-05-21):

---
title: Software Setup
layout: doc
wip: true
---
# Software Setup for Agipix
Prerequisit for this setup is [setting up the Docker](./3_docker_build.Md))

## Setup PX4 interface software stack

This step is tested for the stable Branch `1.16.1 (stable)`

```bash
mkdir -r ~/workspace/agipix_control/src
cd ~/workspace/agipix_control/src
# clone the px4 msgs and manually sync with the Autopilot version
git clone https://github.com/PX4/px4_msgs.git
git clone https://github.com/PX4/PX4-Autopilot.git -b v1.16.1
# Sync
rm -f px4_msgs/msg/*.msg
rm -f px4_msgs/srv/*.srv
cp PX4-Autopilot/msg/*.msg px4_msgs/msg/
cp PX4-Autopilot/srv/*.srv px4_msgs/srv/
cp PX4-Autopilot/msg/versioned/*.msg px4_msgs/msg/
touch px4_version_synced_v1_16_1
rm -rf PX4-Autopilot # optionally remove 
# clone the interface lib
git clone https://github.com/Auterion/px4-ros2-interface-lib -b release/1.16
```
Verify versions
```bash
## to verify compatibility
cd ~/workspace/agipix_control/src/px4-ros2-interface-lib 
./scripts/check-message-compatibility.py -v path/to/px4_msgs/ path/to/PX4-Autopilot/
```
build
```bash
agidocker
# *** Inside agidocker
cd /workspaces/agipix_control
colcon build --packages-select px4_msgs
colcon build --packages-select px4_ros2_cpp

```
### Install [Agi-Logger](https://github.com/SasaKuruppuarachchi/agi_logger)
```bash
cd ~/workspace/logging/src
git clone https://github.com/SasaKuruppuarachchi/agi_logger.git
agidocker
# *** Inside agidocker
cd /workspaces/logging/src/agi_logger
pip install -e .
```

## Sim setup

See [Instructions](../sim/1_setup_sim.md) to continue.

## Agipix Autonomy stack setup

Now we are ready for autonomy setup. See [Instructions](../autonomy/1_perception.md) to continue.

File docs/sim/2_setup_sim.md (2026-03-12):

---
title: Simulation Setup
layout: doc
---
# Setting Up the Agipix Simulation Environment

### Prerequisites for host PC
- Ubuntu 20.04/22.04 Operating System
- NVIDIA GPU (RTX 2070 or higher)
- NVIDIA GPU Driver (recommended version 525.85)

### ROS2 Humble 
&emsp; Follow the latest instructions at the [official page](https://docs.ros.org/en/humble/Installation.html)

### tmux
```bash
sudo apt install tmux
cd && git clone https://github.com/tmux-plugins/tpm ~/.tmux/plugins/tpm
```

&emsp; if you are new to tmux or not already familiar wit tmux
```bash
wget https://raw.githubusercontent.com/SasaKuruppuarachchi/SasaKuruppuarachchi/main/.tmux.conf -P ~/
```
&emsp; go to .tmux.conf and edit line 12 "set -g prefix \`". This charactor "\`" depends on your keyboard layout.

# IsaacSIM Installation
> This documentation is tested for the current stable version 5.1.0. This will be updated as new stable release published

Quick install instructions: [Official Documentation](https://docs.isaacsim.omniverse.nvidia.com/5.1.0/installation/quick-install.html)

```bash
mkdir isaac-sim
cd isaac-sim/
wget https://download.isaacsim.omniverse.nvidia.com/isaac-sim-standalone-5.1.0-linux-x86_64.zip
unzip "isaac-sim-standalone-5.1.0-linux-x86_64.zip" -d ~/isaacsim
rm isaac-sim-standalone-5.1.0-linux-x86_64.zip # optionally clean install artifacts
cd ~/isaacsim
./post_install.sh
```
Setup environemnt vars
```bash
cat <<'EOF' >> ~/.bashrc

# ---------------------------
# ISAAC SIM SETUP
# ---------------------------
# Isaac Sim root directory
export ISAACSIM_PATH="${HOME}/isaacsim"
# Isaac Sim python executable
export ISAACSIM_PYTHON="${ISAACSIM_PATH}/python.sh"
# Isaac Sim app
export ISAACSIM="${ISAACSIM_PATH}/isaac-sim.sh"

# Define an auxiliary function to launch Isaac Sim or run scripts with Isaac Sim's python
# This is done to avoid conflicts between ROS 2 and Isaac Sim's Python environment
isaac_run() {

    # ------------------
    # === VALIDATION ===
    # ------------------
    if [ ! -x "$ISAACSIM_PYTHON" ]; then
        echo "❌ IsaacSim python.sh not found at: $ISAACSIM_PYTHON"
        return 1
    fi
    if [ ! -x "$ISAACSIM" ]; then
        echo "❌ IsaacSim launcher not found at: $ISAACSIM"
        return 1
    fi

    # -------------------------
    # === CLEAN ENVIRONMENT ===
    # -------------------------
    # Unset ROS 2 environment variables to avoid conflicts with Isaac's Python 3.11
    unset ROS_VERSION ROS_PYTHON_VERSION ROS_DISTRO AMENT_PREFIX_PATH COLCON_PREFIX_PATH PYTHONPATH CMAKE_PREFIX_PATH

    # Remove ROS 2 paths from LD_LIBRARY_PATH if present
    local ros_paths=("/opt/ros/humble" "/opt/ros/jazzy" "/opt/ros/iron")
    for ros_path in "${ros_paths[@]}"; do
        export LD_LIBRARY_PATH=$(echo "$LD_LIBRARY_PATH" | tr ':' '\n' | grep -v "^${ros_path}" | paste -sd':' -)
    done

    # -----------------------------
    # === UBUNTU VERSION CHECK ===
    # -----------------------------

    if [ -f /etc/os-release ]; then
        UBUNTU_VERSION=$(grep "^VERSION_ID=" /etc/os-release | cut -d'"' -f2)
    fi

    # If Ubuntu 24.04 -> use the Isaac Sim internal ROS2 Jazzy (ROS2 Jazzy bridge)
    if [[ "$UBUNTU_VERSION" == "24.04" ]]; then
        export ROS_DISTRO=jazzy
        export RMW_IMPLEMENTATION=rmw_fastrtps_cpp
        export LD_LIBRARY_PATH="${LD_LIBRARY_PATH}:${ISAACSIM_PATH}/exts/isaacsim.ros2.bridge/jazzy/lib"
        echo "🧩 Detected Ubuntu 24.04 -> Using ROS_DISTRO=jazzy"
    # If Ubuntu 22.04 -> use the Isaac Sim internal ROS2 Humble (ROS2 Humble bridge)
    else
        export ROS_DISTRO=humble
        export RMW_IMPLEMENTATION=rmw_fastrtps_cpp
        export LD_LIBRARY_PATH="${LD_LIBRARY_PATH}:${ISAACSIM_PATH}/exts/isaacsim.ros2.bridge/humble/lib"
        echo "🧩 Detected Ubuntu ${UBUNTU_VERSION:-unknown} -> Using ROS_DISTRO=humble"
    fi

    # ---------------------
    # === RUN ISAAC SIM ===
    # ---------------------
    if [ $# -eq 0 ]; then
        # No args → Launch full Isaac Sim GUI
        echo "🧠 Launching Isaac Sim GUI..."
        "${ISAACSIM}"

    elif [[ "$1" == --* ]]; then
        # Arguments start with "--" → pass them to Isaac Sim executable
        echo "⚙️  Launching Isaac Sim with options: $*"
        "${ISAACSIM}" "$@"

    elif [ -f "$1" ]; then
        # First argument is a Python file → run with Isaac Sim's Python
        local SCRIPT_PATH="$1"
        shift
        echo "🚀 Running Python script with Isaac Sim: $SCRIPT_PATH"
        "${ISAACSIM_PYTHON}" "$SCRIPT_PATH" "$@"

    else
        # Unrecognized input
        echo "❌ Unknown argument or file not found: '$1'"
        echo "Usage:"
        echo "  isaac_run                 → launch GUI"
        echo "  isaac_run my_script.py    → run script with IsaacSim Python"
        echo "  isaac_run --headless ...  → launch IsaacSim with CLI flags"
        return 1
    fi
}
alias agisim="cd ~/workspace/raicam-ros/src/isaac_ros_common/ && ./run_sim.sh"
export ROS_DOMAIN_ID=3
EOF
source ~/.bashrc
```

Running IsaacSIM

### Nucleus Server
> Depreciated

&emsp; [Download](https://docs.omniverse.nvidia.com/install-guide/latest/workstation-install.html) and install Omniverse Launcher and install [Nucleus Server](https://docs.omniverse.nvidia.com/launcher/latest/workstation-launcher.html#collaboration-tab)
&emsp; Go to the library and install ISAACSIM.

### Enable ROS2 extension
&emsp; Open IsaacSIM > Window > Extension > ROS2 bridge – enable (Autoload)

### Installing Qgroundcontrol (for PX4 based implementations)
&emsp; Follow the latest instructions at the [official page](https://docs.qgroundcontrol.com/master/en/qgc-user-guide/getting_started/download_and_install.html)

```bash
sudo usermod -aG dialout "$(id -un)"
```
(Optional) Disable ModemManager On some Ubuntu-based systems, ModemManager can claim serial ports that QGC needs. If you don't use it elsewhere, mask or remove it.
```bash
# preferred: stop and mask the service
sudo systemctl mask --now ModemManager.service

# or, if you’d rather remove the package
sudo apt remove --purge modemmanager
```
On the command prompt, enter:
```bash
sudo apt install gstreamer1.0-plugins-bad gstreamer1.0-libav gstreamer1.0-gl -y
sudo apt install libfuse2 -y
sudo apt install libxcb-xinerama0 libxkbcommon-x11-0 libxcb-cursor-dev -y
```
To install QGroundControl:

1. Download [QGroundControl-x86_64.AppImage](https://d176tv9ibo4jno.cloudfront.net/latest/QGroundControl-x86_64.AppImage).

2. Make the AppImage executable

```bash
chmod +x QGroundControl-x86_64.AppImage
./QGroundControl-x86_64.AppImage
```

### PX4 firmware

```bash
# Linux packages
sudo apt install git make cmake python3-pip

# Python packages
pip install kconfiglib jinja2 empy jsonschema pyros-genmsg packaging toml numpy future

cd $HOME
git clone https://github.com/PX4/PX4-Autopilot.git -b v1.16.1 --recursive
cd PX4-Autopilot
make px4_sitl_default none
```
if PX4 launched properly you can exit out of it.
&emsp; For further information [visit here](https://docs.px4.io/main/en/dev_setup/building_px4.html)

##### (Optional) If an `externally-managed-environment` Use an venv
```bash
sudo apt install python3-venv python3-pip python3-full
cd PX4-Autopilot
# setup and activate venv
python3 -m venv .venv
source .venv/bin/activate
pip install --upgrade pip
pip install empy jinja2 numpy toml pyyaml packaging
# install and fix python deps
pip install kconfiglib jinja2 empy jsonschema pyros-genmsg packaging toml numpy future
pip uninstall empy
pip install empy==3.3.4
# Build Px4 
make clean
make px4_sitl_default none
```

To synchronise the time stamps with the simulator we need to set the parameter [UXRCE_DDS_SYNCT](https://docs.px4.io/main/en/advanced_config/parameter_reference.html#UXRCE_DDS_SYNCT) to `false`. To do that,
1. Open the rcS file at `/PX4-Autopilot/ROMFS/px4fmu_common/init.d-posix/rcS`
2. Paste the following line before ´#Autostart ID´
```bash
param set-default UXRCE_DDS_SYNCT 0
param set-default UXRCE_DDS_DOM_ID 3
```
3. Rebuild the firmware
```bash
cd $HOME
cd PX4-Autopilot
make px4_sitl_default none
```
4. Make sure to set the parameter `use_sim_time` (of each ROS2 node) to `true`

### Pegusus simulaotor
&emsp; Cloning into the repo and the assets
```bash
cd $HOME
git clone https://github.com/SasaKuruppuarachchi/PegasusSimulator.git
cd PegasusSimulator/extensions/pegasus.simulator/pegasus/simulator/assets/Worlds
git clone https://github.com/SasaKuruppuarachchi/isaac_envs.git
```
&emsp; Installing the extension as a library

```bash
cd ~/isaacsim
./python.sh -m pip install --editable  /home/sasa/PegasusSimulator/extensions/pegasus.simulator
```

> [!NOTE]
> For the first time, launching Isaac Sim takes a very long time.
> Isaac Sim must be fully launched to spawn the robot.

### Enabling Pegasus Simulator in Isaacsim (First Operation)

1. Launch ``isaac_run`` application.

2. Open the Window->extensions on the top menubar inside Isaac Sim.
   

3. On the Extensions manager menu, we can enable or disable extensions. By pressing the settings button, we can 
add a path to the Pegasus-Simulator repository.

   

4. The path inserted should be the path to the repository followed by ``/extensions``.

   

5. After adding the path to the extension, we can enable the Pegasus Simulator extension on the third-party tab.

   

When enabling the extension for the first time, the python requirements should be install automatically for the build in 
``ISAACSIM_PYTHON`` , and after a few seconds, the Pegasus widget GUI should pop-up.

6. The Pegasus Simulator window should appear docked to the bottom-right section of the screen.

   

## Post setups
### Download assets
- Download assets from [Official page](https://docs.isaacsim.omniverse.nvidia.com/5.1.0/installation/download.html) and same them in `~/isaacsim/assets/` 
- then `mkdir ~/isaacsim/assets/Isaac/5.1/NVIDIA`
- Open `~/isaacsim/exts/isaacsim.asset.browser/config/extension.toml` and add the asset paths at 

    ```toml
    [settings]
    # Root folder URLs to list and monitor.
    exts."isaacsim.asset.browser".folders = [
        # asset paths here
    ]
    ```

- Open `~isaacsim/exts/isaacsim.storage.native/config/extension.toml` and replace persistent.isaac.asset_root.default with `persistent.isaac.asset_root.default = "/home/sasa/isaacsim/assets/Isaac/5.1"`

### Add Lidar definitions
To replicate Mid360 lidar in the Agipix we create this custom Lidar model in Isaacsim.

- Copy Mid360 usda file `cp ~/PegasusSimulator/assets/lidar/Mid_360.usda ~/isaacsim/assets/Isaac/5.1/Isaac/Sensors/NVIDIA/Mid_360.usda`
- Open `~/isaacsim/exts/isaacsim.sensors.rtx/isaacsim/sensors/rtx/impl/supported_lidar_configs.py` and add `"/Isaac/Sensors/NVIDIA/Mid_360.usda": set(),` under the `SUPPORTED_LIDAR_CONFIGS`

## Running the Simulation

1. Open a new terminal to launch the simulator
   ```bash
   cd $ISAAC_ROS_DEV_DIR/src/isaac_ros_common/ && ./run_sim.sh
   # press ENTER after moving to the right pane to launch IsaacSim
   ```

2. In a new terminal run the docker container
   ```bash
   runagi
   ```
3. Controlling the drone

Follow the instructions in the top right pane of docker tmux window

4. Opening the UI

   1. Open up a [Foxglow](https://app.foxglove.dev/) account and bavigate to the dashboard
   2. Open connection with "ws://localhost:8765"

Now we are ready for autonomy setup. See [Instructions](../autonomy/1_perception.md) to continue.

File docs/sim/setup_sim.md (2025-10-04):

---
title: Simulation Setup
layout: doc
---
# Setting Up the Agipix Simulation Environment

### Prerequisites for host PC
- Ubuntu 20.04/22.04 Operating System
- NVIDIA GPU (RTX 2070 or higher)
- NVIDIA GPU Driver (recommended version 525.85)

### Optional Docker
All the deployment is dockerised [Setup Docker](https://github.com/RAICAM-EU-Project/isaac_ros_common) 
- branch `agipix-hard` for Hardware
- Branch `agipix-sim` for Software

### ROS2 Humble 
&emsp; Follow the latest instructions at the [official page](https://docs.ros.org/en/humble/Installation.html)

### tmux
```bash
sudo apt install tmux
cd && git clone https://github.com/tmux-plugins/tpm ~/.tmux/plugins/tpm
```

&emsp; if you are new to tmux or not already familiar wit tmux
```bash
wget https://raw.githubusercontent.com/SasaKuruppuarachchi/SasaKuruppuarachchi/main/.tmux.conf -P ~/
```
&emsp; go to .tmux.conf and edit line 12 "set -g prefix \`". This charactor "\`" depends on your keyboard layout.

### Nucleus Server
&emsp; [Download](https://docs.omniverse.nvidia.com/install-guide/latest/workstation-install.html) and install Omniverse Launcher and install [Nucleus Server](https://docs.omniverse.nvidia.com/launcher/latest/workstation-launcher.html#collaboration-tab)
&emsp; Go to the library and install ISAACSIM.

### Enable ROS2 extension
&emsp; Open IsaacSIM > Window > Extension > ROS2 bridge – enable (Autoload)

### Installing Qgroundcontrol (for PX4 based implementations)
&emsp; Follow the latest instructions at the [official page](https://docs.qgroundcontrol.com/master/en/qgc-user-guide/getting_started/download_and_install.html)

### Installing docker
&emsp; Follow the latest instructions at the [official docker page](https://docs.docker.com/engine/install/ubuntu/)

### Installing Portainer CE
&emsp; Portainer CE is an open-source GUI for creating and managing docker containers. Install it following [these instructions](https://docs.portainer.io/start/install-ce/server/docker/linux)

### Installing Nvidia Docker
&emsp; Install the Nvidia Container toolkit with [These Instructions](https://docs.nvidia.com/datacenter/cloud-native/container-toolkit/latest/install-guide.html)

### PX4 firmware

```bash
# Linux packages
sudo apt install git make cmake python3-pip

# Python packages
pip install kconfiglib jinja2 empy jsonschema pyros-genmsg packaging toml numpy future

cd $HOME
git clone https://github.com/PX4/PX4-Autopilot.git --recursive
cd PX4-Autopilot
make px4_sitl_default none
```
if PX4 launched properly you can exit out of it.
&emsp; For further information [visit here](https://docs.px4.io/main/en/dev_setup/building_px4.html)

To synchronise the time stamps with the simulator we need to set the parameter [UXRCE_DDS_SYNCT](https://docs.px4.io/main/en/advanced_config/parameter_reference.html#UXRCE_DDS_SYNCT) to `false`. To do that,
1. Open the rcS file at `/PX4-Autopilot/ROMFS/px4fmu_common/init.d-posix/rcS`
2. Paste the following line before ´#Autostart ID´
```bash
param set-default UXRCE_DDS_SYNCT 0
```
3. Rebuild the firmware
```bash
cd $HOME
cd PX4-Autopilot
make px4_sitl_default none
```
4. Make sure to set the parameter `use_sim_time` (of each ROS2 node) to `true`

### Pegusus simulaotor
&emsp; Add the following lines to your ~/.bashrc or ~/.zshrc file.
```bash
# Isaac Sim root directory
export ISAACSIM_PATH="${HOME}/.local/share/ov/pkg/isaac_sim-4.1.0"
# Isaac Sim python executable
alias ISAACSIM_PYTHON="${ISAACSIM_PATH}/python.sh"
# Isaac Sim app
alias ISAACSIM="${ISAACSIM_PATH}/isaac-sim.sh"
# Change {user} accordingly
LD_LIBRARY_PATH=$LD_LIBRARY_PATH:/home/{user}/.local/share/ov/pkg/isaac_sim-2023.1.1/exts/omni.isaac.ros2_bridge/humble/lib
```
&emsp; Installing the extension as a library

```bash
# Go to the repository of the pegasus simulator
cd PegasusSimulator

# Go into the extensions directory
cd extensions

# Run the pip command using the built-in python interpreter
ISAACSIM_PYTHON -m pip install --editable pegasus.simulator
```

> [!NOTE]
> For the first time, launching Isaac Sim takes a very long time.
> Isaac Sim must be fully launched to spawn the robot.

### Enabling Pegasus Simulator in Isaacsim (First Operation)

1. Launch ``ISAACSIM`` application.

2. Open the Window->extensions on the top menubar inside Isaac Sim.
   

3. On the Extensions manager menu, we can enable or disable extensions. By pressing the settings button, we can 
add a path to the Pegasus-Simulator repository.

   

4. The path inserted should be the path to the repository followed by ``/extensions``.

   

5. After adding the path to the extension, we can enable the Pegasus Simulator extension on the third-party tab.

   

When enabling the extension for the first time, the python requirements should be install automatically for the build in 
``ISAACSIM_PYTHON`` , and after a few seconds, the Pegasus widget GUI should pop-up.

6. The Pegasus Simulator window should appear docked to the bottom-right section of the screen.

   

## Installation - Docker contrainer

1. Set your workspace definitions and Clone the repo to your ros2 workspace. replace "your_branch" with "agipix_sim" for the drone
   ```bash
   echo "export WORKSPACES_DIR='/home/sasa/workspace'" >> ~/.bashrc
   echo "export ISAAC_ROS_DEV_DIR='/home/sasa/workspace/raicam-ros'" >> ~/.bashrc
   source ~/.bashrc
   cd $ISAAC_ROS_DEV_DIR && git clone https://github.com/RAICAM-EU-Project/isaac_ros_common.git -b your_branch
   
   # set up DDS for ROS2 communication
   cd $WORKSPACES_DIR && mkdir dds && cd dds
   git clone https://github.com/eProsima/Micro-XRCE-DDS-Agent.git

   # Set up control stack
   cd $WORKSPACES_DIR && mkdir agipix_control && cd agipix_control
   git clone https://github.com/SasaKuruppuarachchi/px4_ros2_offboard.git
   git clone https://github.com/PX4/px4_msgs.git
   git clone https://github.com/SasaKuruppuarachchi/agipix_user_interfaces.git

   ```

2. First run of the Docker container
   ```bash
   # this will start the compose the docker container and start it. First run might take up to 15 Minutes
   cd $WORKSPACES_DIR/raicam-ros/src/isaac_ros_common/scripts/ && ./run_dev.sh

   cd /workspaces/dds/Micro-XRCE-DDS-Agent/
   mkdir build && cd build
   cmake ..
   make
   sudo make install
   sudo ldconfig /usr/local/lib/

   cd /workspaces/agipix_control && colcon build
   source /workspaces/agipix_control/install/setup.bash
   ```

## Running the Simulation

1. Open a new terminal to launch the simulator
   ```bash
   cd $ISAAC_ROS_DEV_DIR/src/isaac_ros_common/ && ./run_sim.sh
   # press ENTER after moving to the right pane to launch IsaacSim
   ```

2. In a new terminal run the docker container
   ```bash
   source /workspaces/agipix_control/install/setup.bash

   # this will run the control stack on docker
   cd /workspaces/agipix_control/src/px4_ros2_offboard/tmux/ && ./start.sh
   ```
3. Controlling the drone

Follow the instructions in the top right pane of docker tmux window

4. Opening the UI

   1. Open up a [Foxglow](https://app.foxglove.dev/) account and bavigate to the dashboard
   2. Open connection with "ws://localhost:8765"

Now we are ready for autonomy setup. See [Instructions](../autonomy/perception.md) to continue.

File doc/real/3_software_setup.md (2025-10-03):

# Sowftware Setup for Agipix

All the deployment is dockerised [Setup Docker](https://github.com/RAICAM-EU-Project/isaac_ros_common) 
- branch `agipix-hard` for Hardware
- Branch `agipix-sim` for Software

Follow instructions to setup docker

## Sim setup

See [Instructions](../sim/setup_sim.md) to continue.

## Agipix Autonomy stack setup

Now we are ready for autonomy setup. See [Instructions](./4_agipix_autonomy.md) to continue.

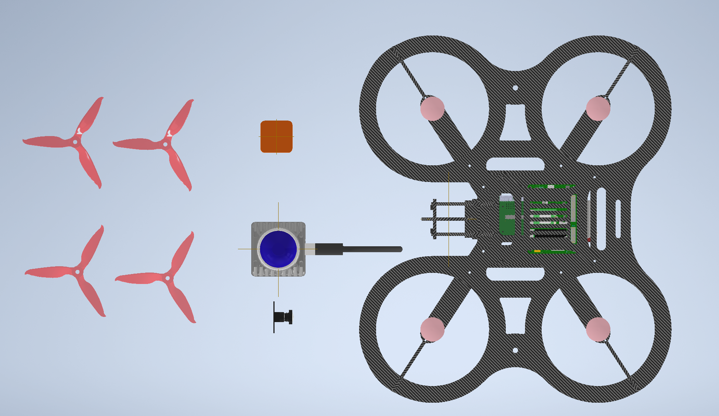
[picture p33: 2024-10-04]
assets/images/real/making/Agipix_v2_assembly_cad.png

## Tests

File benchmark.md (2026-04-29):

---
title: Platform Benchmark Methodology
layout: doc
permalink: /benchmark.html
---

# Benchmark Methodology for Aerial Platforms

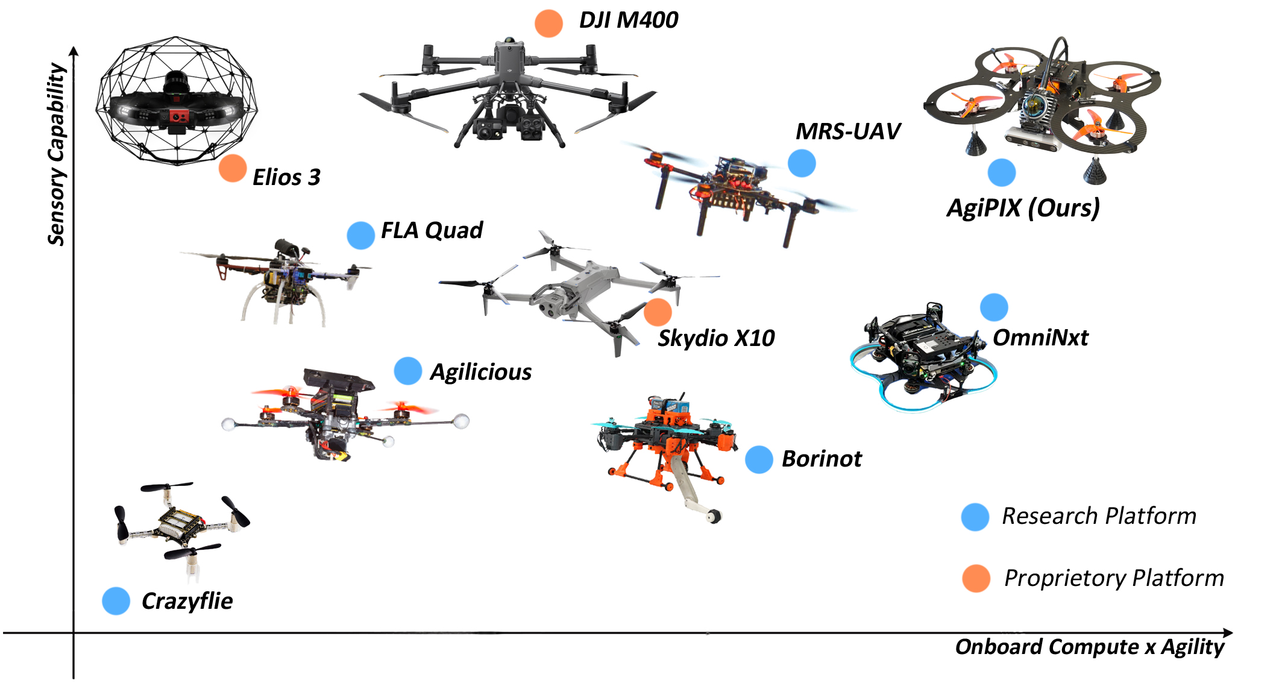
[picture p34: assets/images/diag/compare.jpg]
Platform comparison figure


<script src="https://polyfill.io/v3/polyfill.min.js?features=es6"></script>
<script id="MathJax-script" async src="https://cdn.jsdelivr.net/npm/mathjax@3/es5/tex-mml-chtml.js"></script>

## Evaluating Platform Intelligence and Agility

Designing a compact, actively sensed aerial robotics platform for indoor environments demands careful trade-offs between raw compute power, agility, and the payload's sensory capability. Traditional benchmarks often evaluate these metrics in isolation (e.g., pure AI TOPS for compute, or Thrust-to-Weight Ratio for agility). However, the true efficacy of an autonomous platform lies in its combined capacity to process complex environments and act upon them rapidly.

To quantitatively evaluate and compare AgiPIX against existing industrial and research platforms, we define a composite benchmarking methodology.

<br>

### 1. Composite Compute Score

The compute architecture of aerial platforms must balance both high-level AI inference (for perception and planning) and robust real-time responsiveness (for state estimation and control OS loops). 

To reflect this, our benchmark establishes a **Composite Score** ($$ C $$) combining:
- **CPU PassMark ($$ P $$):** Representing general-purpose compute required for deterministic control tasks.
- **Compute TOPS ($$ T $$):** Representing AI acceleration capabilities.

These values are normalized against the maximum known bounds within the dataset ($$ P_{\max} $$ and $$ T_{\max} $$). A weighting factor $$ \alpha $$ is utilized to emphasize that in autonomous aerial robotics, a strong CPU backbone is fundamental to ensure real-time stability, even if pure AI accelerators are present. The composite score is defined as:

$$
C = \min\left(1, \; \alpha \frac{P}{P_{\max}} + (1 - \alpha) \frac{T}{T_{\max}}\right)
$$

*(In our evaluation, we utilize $$ \alpha = 0.6 $$ to prioritize CPU performance).*

<br>

### 2. The Agility Multiplier

Raw intelligence must be actionable. We utilize the Thrust-to-Weight Ratio (TWR) as a proxy for platform **Agility** ($$ A $$). By multiplying the Composite Score by the Agility, we derive a unified metric: 

$$
M = C \times A
$$

This unified metric, $$ M $$, represents the drone's holistic ability to compute decisions and execute physical maneuvers rapidly.

<br>

### 3. Sensory Capability Mapping

The final analysis maps this unified compute-agility metric ($$ M $$) against a qualitative **Sensory Capability** scale ($$ S \in [1, 5] $$). 

Plotting $$ S $$ against $$ M $$ reveals the Pareto front of design trade-offs—demonstrating how different platforms allocate weight and volume budgets between "smart agility" and heavy sensory payloads.

<br>
---

## Benchmark Script Output

Below is the composite performance evaluation for the first 10 systems evaluated:

```text
Composite performance example (first 10 systems):
         Platform  CPU_PassMark  Compute_TOPS  Composite_Score
         DJI M400          2418    100.000000         0.411383
       SkyDio X10          2418    117.000000         0.454695
Flyability Elios3          1343     21.000000         0.140485
        Crazyflie            10      0.000336         0.000649
         FLA-Quad          3383      0.050000         0.219234
           Bornot          6190      0.134000         0.401248
          MRS UAV          9264      0.226000         0.600576
       Agilicious          1343     13.300000         0.120867
          OmniNxt          2418    117.000000         0.454695
    AgiPIX (Ours)          2418    157.000000         0.556606
```

## Source Code

The full logic and data extraction is available in `bench_platforms.py`:

```python
import pandas as pd
import matplotlib.pyplot as plt
from typing import Iterable, Tuple

# -----------------------------------------
# CONFIG
# -----------------------------------------
# Compute in TOPS (or consistent TOPS unit)
# Agility = TWR
# Sensory capability = 1–5 scale
# Diagonal span in millimeters (approximate; update with real values)
# CPU PassMark is the CPU benchmark score (use None if unknown)

#TOPS to TFLOPS conversion (if needed): # ref https://forums.developer.nvidia.com/t/what-is-tops-of-tx2-board/117375/6
# "In general, the performance can be represent theoretically to X TFLOPS for FP16 or 2X TOPS for INT8 if both type are supported"

## assumptions made for the sake of comparison
## Though not explicitly stated follwoing assumptions are made for the TOPS estimation
# DJI M400: 100 TOPS ref https://enterprise.dji.com/manifold-3
# SkyDio X10: 117 TOPS, qrb5165 Cortex A77 - Jetson Orin SOC Most likely NX due to the size ref https://www.skydio.com/x10/technical-specs, https://www.nvidia.com/en-us/autonomous-machines/embedded-systems/jetson-orin/
# Flyability Elios3: 21 TOPS -2.12 TFLOPS Nvidia Xavier NX ref https://nexxis.com.au/wp-content/uploads/2020/11/20220519_E3_Tech_Spec_web_version.pdf, https://www.nvidia.com/en-us/autonomous-machines/embedded-systems/jetson-xavier-nx/
# Crazyflie: 0.000336 TOPS - STM32F405 ref https://www.bitcraze.io/2024/01/crazyflie-2-1-now-with-10-tops-of-compute/
# FLA-Quad: 0.05 TOPS Intel i7-5557U processor refhttps://arxiv.org/abs/1712.02052
# Bornot: 0.134 TOPS - i7-8650U ref https://arxiv.org/pdf/2307.14686
# MRS UAV: 0.226 TOPS - i7-10710U ref https://arxiv.org/pdf/2306.07229
# Agilicious: 13.3 TOPS - 1.33 TFLOPS Nvidia Jetson TX2 ref #TOPS to TFLOPS conversion (if needed): # ref https://forums.developer.nvidia.com/t/what-is-tops-of-tx2-board/117375/6
        # "In general, the performance can be represent theoretically to X TFLOPS for FP16 or 2X TOPS for INT8 if both type are supported"
# OmniNxt: 117 TOPS - Nvidia Jetson NX ref https://www

"""
Compute Capability Estimate – Intel Core i7-10710U (CPU-only)

This system uses an Intel Core i7-10710U:
    - 6 cores / 12 threads
    - Base clock: 1.1 GHz
    - Turbo clock: up to 4.7 GHz
    - Supports AVX2 (256-bit SIMD)
    - No dedicated NPU / AI accelerator

CPUs do not have an official TOPS rating. However, we can estimate a 
theoretical upper bound for floating-point throughput using AVX2.

Assumptions for peak single-precision FLOPS:
    - AVX2 = 256-bit vector width
    - 256 bits = 8 x 32-bit floats per vector instruction
    - Assume 1 vector FMA per cycle (ideal case)
    - Use max turbo frequency (4.7 GHz)
    - All 6 cores fully utilized

Theoretical peak FLOPS:

    FLOPS ≈ cores × FLOPs_per_cycle × frequency

    FLOPS ≈ 6 × 8 × 4.7e9
           ≈ 225.6e9 FLOPS
           ≈ 225 GFLOPS
           ≈ 0.226 TFLOPS
           ≈ 0.226 TOPS (if counting 1 FLOP as 1 operation)

Important:
    - This is a best-case theoretical peak.
    - Real sustained performance will be significantly lower.
    - Memory bandwidth, cache misses, branching, and non-vectorized code
      reduce actual throughput.
    - This is NOT comparable to dedicated AI accelerators (NPUs/GPUs)
      that achieve tens to thousands of TOPS.

Practical takeaway:
    Expect roughly 0.2–0.3 TOPS theoretical peak CPU compute.
    Real AI inference throughput depends heavily on optimization 
    (e.g., OpenVINO, ONNX Runtime, quantization).
"""

# Toggle log scale for compute (TOPS) axis in plot 1
USE_LOG_SCALE = False

# Toggle to use Composite_Score for plots 1–3 instead of compute-based metrics
USE_COMPOSITE_FOR_PLOTS = True

DEFAULT_ALPHA = 0.6 # for robotics heavy workloads, we may want to prioritize CPU performance more than pure compute, as it can impact overall system responsiveness and real-time control. However, this can be adjusted based on specific use cases and preferences.
# benchmark = Nvidia Jetson agx orin with CPU PassMark score of 5653 compute capability of 275 TOPS https://www.nvidia.com/en-us/autonomous-machines/embedded-systems/jetson-orin/
REFERENCE_CPU_PASSMARK = 5653
REFERENCE_MAX_TOPS = 725

# -----------------------------------------
# METRIC UTILITIES
# -----------------------------------------

def _clamp(value: float, minimum: float = 0.0, maximum: float = 1.0) -> float:
    return max(minimum, min(value, maximum))

def composite_performance_score(
    cpu_score: float,
    ai_tops: float,
    max_cpu_score: float,
    max_ai_tops: float,
    alpha: float = DEFAULT_ALPHA,
) -> Tuple[float, str]:
    """
    Compute a normalized composite performance score from CPU PassMark and AI TOPS.

    Assumptions:
        - CPU score and TOPS are not directly comparable, so both are normalized to [0, 1].
        - The result is a weighted combination where alpha controls CPU importance.
        - Inputs may be missing or zero; division-by-zero is avoided and outputs are clamped.
    """

    safe_max_cpu = max(max_cpu_score, 0.0)
    safe_max_ai = max(max_ai_tops, 0.0)

    normalized_cpu = cpu_score / safe_max_cpu if safe_max_cpu > 0 else 0.0
    normalized_ai = ai_tops / safe_max_ai if safe_max_ai > 0 else 0.0

    composite = _clamp(alpha * normalized_cpu + (1.0 - alpha) * normalized_ai)

    if composite > 0.75:
        label = "High Performance"
    elif composite >= 0.4:
        label = "Balanced / Mid-range"
    else:
        label = "Entry-level"

    return composite, label

def plot_cpu_vs_tops(systems: Iterable[Tuple[str, float, float]], title: str) -> None:
    """
    Plot CPU PassMark vs AI TOPS for a list of systems.

    Each system is (name, cpu_passmark, ai_tops).
    """

    plt.figure()
    for name, cpu_score, ai_tops in systems:
        plt.scatter(cpu_score, ai_tops)
        plt.text(cpu_score, ai_tops, name)

    plt.xlabel("CPU PassMark")
    plt.ylabel("AI Compute (TOPS)")
    plt.title(title)
    plt.grid(True)
    plt.show()

def plot_scatter_with_labels(
    df: pd.DataFrame,
    x_key: str,
    y_key: str,
    xlabel: str,
    ylabel: str,
    title: str,
    log_x: bool = False,
) -> None:
    plt.figure()
    plt.scatter(df[x_key], df[y_key])

    for _, row in df.iterrows():
        plt.text(row[x_key], row[y_key], row["Platform"])

    plt.xlabel(xlabel)
    plt.ylabel(ylabel)
    plt.title(title)
    if log_x:
        plt.xscale("log")
    plt.grid(True)
    plt.show()

def build_dataframe() -> pd.DataFrame:
    data = [
        # name, compute_TOPS, cpu_passmark, agility_TWR, sensory_capability, diagonal_span_mm
        ["DJI M400",         100, 2418, 2.30, 5, 1240],
        ["SkyDio X10",       117, 2418, 2.60, 3, 1023],
        ["Flyability Elios3",21, 1343, 1.80, 4, 480],
        ["Crazyflie",        0.000336, 10, 2.26, 1, 92],
        ["FLA-Quad",         0.05, 3383, 2.38, 3.5, 300],
        ["Bornot",           0.134, 6190, 3.50, 2, 516],
        ["MRS UAV",          0.226, 9264, 2.50, 4, 792],
        ["Agilicious",       13.3, 1343, 5.00, 2.5, 382],
        ["OmniNxt",          117, 2418, 4.24, 3, 250],
        ["AgiPIX (Ours)",    157, 2418, 3.50, 4, 495],  # Orin NX 16gb (Super)
    ]

    df = pd.DataFrame(
        data,
        columns=[
            "Platform",
            "Compute_TOPS",
            "CPU_PassMark",
            "Agility_TWR",
            "Sensory_1to5",
            "Diagonal_Span_mm",
        ],
    )

    max_cpu_score = df["CPU_PassMark"].max()
    max_ai_tops = df["Compute_TOPS"].max()

    df["Compute_x_Agility"] = df["Compute_TOPS"] * df["Agility_TWR"]
    df["Compute_x_Agility_per_Span"] = df["Compute_x_Agility"] / df["Diagonal_Span_mm"]

    composite_results = df.apply(
        lambda row: composite_performance_score(
            cpu_score=row["CPU_PassMark"],
            ai_tops=row["Compute_TOPS"],
            max_cpu_score=max_cpu_score,
            max_ai_tops=max_ai_tops,
        ),
        axis=1,
    )
    df[["Composite_Score", "Composite_Label"]] = pd.DataFrame(
        composite_results.tolist(), index=df.index
    )

    df["Composite_Score_x_Agility"] = df["Composite_Score"] * df["Agility_TWR"]
    df["Composite_Score_x_Agility_per_Span"] = (
        df["Composite_Score_x_Agility"] / df["Diagonal_Span_mm"]
    )

    return df

def main() -> None:
    df = build_dataframe()

    example_systems = df.loc[
        :9, ["Platform", "CPU_PassMark", "Compute_TOPS", "Composite_Score", "Composite_Label"]
    ]
    print("Composite performance example (first 10 systems):")
    print(example_systems.to_string(index=False))

    plot1_x = "Composite_Score" if USE_COMPOSITE_FOR_PLOTS else "Compute_TOPS"
    plot1_xlabel = "Composite Score" if USE_COMPOSITE_FOR_PLOTS else "Compute (TOPS)"
    plot1_title = (
        "Agility vs Composite Score" if USE_COMPOSITE_FOR_PLOTS else "Agility vs Onboard Compute"
    )

    plot_scatter_with_labels(
        df,
        x_key=plot1_x,
        y_key="Agility_TWR",
        xlabel=plot1_xlabel,
        ylabel="Agility (TWR)",
        title=plot1_title,
        log_x=USE_LOG_SCALE and not USE_COMPOSITE_FOR_PLOTS,
    )

    plot3_x = (
        "Composite_Score_x_Agility_per_Span"
        if USE_COMPOSITE_FOR_PLOTS
        else "Compute_x_Agility_per_Span"
    )
    plot3_xlabel = (
        "Composite Score × Agility / Diagonal Span (mm)"
        if USE_COMPOSITE_FOR_PLOTS
        else "Compute × Agility / Diagonal Span (mm)"
    )
    plot3_title = (
        "Sensory Capability vs Composite Score × Agility / Diagonal Span"
        if USE_COMPOSITE_FOR_PLOTS
        else "Sensory Capability vs Compute × Agility / Diagonal Span"
    )

    # plot_scatter_with_labels(
    #     df,
    #     x_key=plot3_x,
    #     y_key="Sensory_1to5",
    #     xlabel=plot3_xlabel,
    #     ylabel="Sensory Capability (1–5)",
    #     title=plot3_title,
    # )

    plot2_x = "Composite_Score_x_Agility" if USE_COMPOSITE_FOR_PLOTS else "Compute_x_Agility"
    plot2_xlabel = "Composite Score × Agility" if USE_COMPOSITE_FOR_PLOTS else "Compute × Agility"
    plot2_title = (
        "Sensory Capability vs Composite Score × Agility"
        if USE_COMPOSITE_FOR_PLOTS
        else "Sensory Capability vs Compute × Agility"
    )

    plot_scatter_with_labels(
        df,
        x_key=plot2_x,
        y_key="Sensory_1to5",
        xlabel=plot2_xlabel,
        ylabel="Sensory Capability (1–5)",
        title=plot2_title,
    )

if __name__ == "__main__":
    main()

```

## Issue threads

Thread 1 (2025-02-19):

Landing Gear redesign and damper

SasaKuruppuarachchi, 2025-02-19:
## Goals
- [x] Design and print new shock absorbing pads
- [x] Edit the Al landing gear with thread
- [ ] Fix to the frame

Closed 2025-03-09.

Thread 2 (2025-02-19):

Redesign of the side impact strut

SasaKuruppuarachchi, 2025-02-19:
## Goals
- Increase compliance with the Side impact strut

## Tasks
- [ ] Design the lower joint
- [ ] Design the Upper Joint
- [ ] Print Joints
- [ ] Edit the struts
- [ ] Put together

Closed 2025-03-09.

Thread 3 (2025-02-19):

Vibration damped Lidar cage v1

SasaKuruppuarachchi, 2025-02-19:
Create the vibration damped mounts for the lidar
## Tasks

- [ ] Design
- [ ] CF cut
- [ ] Wait for the rubber dampers
- [ ] Put together

Closed 2025-03-09.

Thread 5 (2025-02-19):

Flight test - Manual to verify Lidar odometry

SasaKuruppuarachchi, 2025-02-19:
Since the crash Odometry is not stable

Closed 2025-03-09.

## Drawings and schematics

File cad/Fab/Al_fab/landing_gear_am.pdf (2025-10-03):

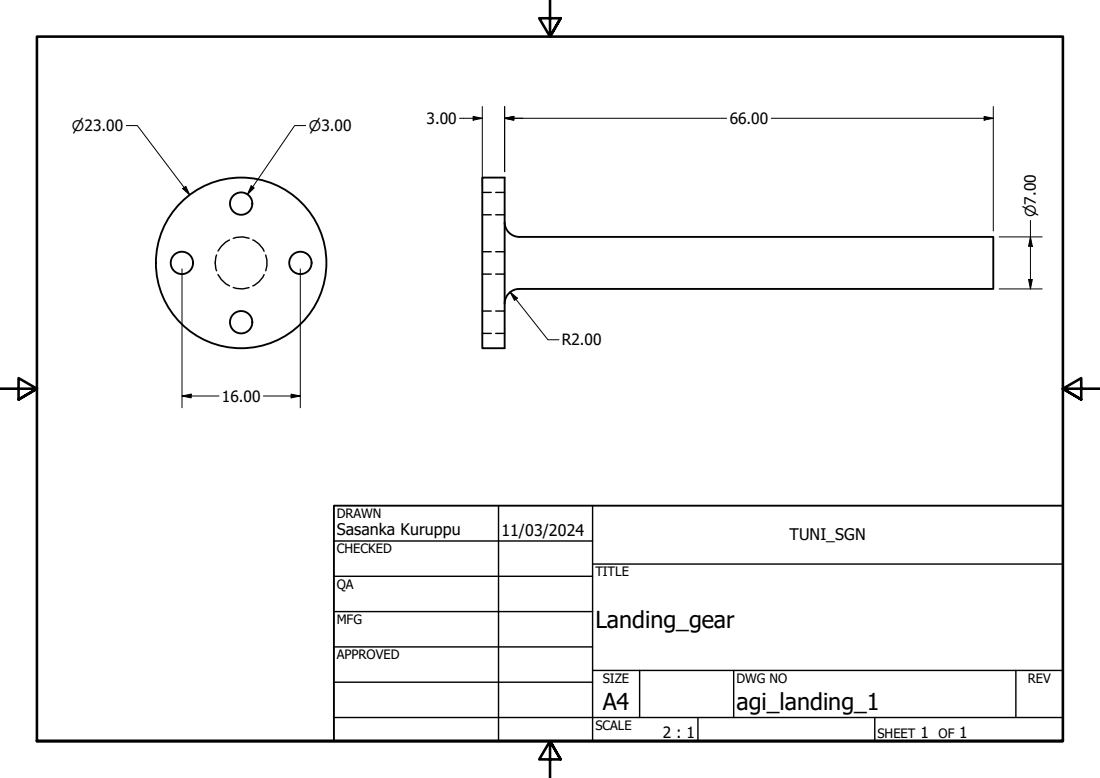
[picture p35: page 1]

DRAWN Sasanka Kuruppu | 11/03/2024 | TUNI_SGN

CHECKED

MFG

APPROVED

SIZE A4 | DWG NO agi_landing_1 | REV

SCALE 2 : 1 | | SHEET 1 OF 1

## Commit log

2024-10-04 commit with v2 stps
    [Agipix_v2 _sim.stl]
2024-10-06 unit changed stp and stl files
    [Agipix_v2 _sim.stl, prop_ccw_5.stl, prop_cw_5.stl]
2024-10-06 stl sensors
    [camera.stl, cube_orange.stl, lidar.stl]
2025-10-03 Restructured repo with everythin minus site
    [1_5mm_500x600.dxf, 1_5mm_500x600_1.dxf, 4mm_500x500.dxf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]
2025-10-03 Add professional GitHub Pages documentation site with MkDocs Material
2025-10-03 Revert "Add professional GitHub Pages documentation site with MkDocs Material"
2025-10-03 Add comprehensive documentation for Agipix hardware and software setup
    - Created index.md for Agipix documentation hub with navigation paths.
    - Added detailed guide for hardware assembly in 1_hardware_assembly.md.
    - Introduced flashing instructions for Jetson and carrier in 2_flashing_hardware.md.
    - Documented software setup process in 3_software_setup.md.
    - Explained Agipix autonomy framework in 4_agipix_autonomy.md.
    - Included configuration snippet for Hadron carrier in hadron_cfg.txt.
    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
2025-10-03 Fix image path formatting in hardware assembly documentation
2025-10-04 Refactor documentation styles to use accessible white accents for links and buttons
2025-10-04 Refactor documentation styles to use accessible blue accents for links and buttons
2025-10-04 Update documentation links for autonomy framework and add new perception page
2025-10-04 Refactor documentation links for autonomy framework and simulation setup; add new perception and planning control pages
2025-10-04 Update documentation links for autonomy framework to reflect new directory structure
2025-10-04 Update autonomy framework documentation links to reflect new file structure
2025-10-07 Update button text color in documentation styles for improved readability
2025-10-07 Update button text color for improved visibility and clarity in documentation links
2025-10-07 Add new datasheets, images, and videos; update paths in documentation
    - Added new datasheets: pinouts_hadron.pdf, spec_1CBG117R.pdf, usbc.pdf
    - Added various images related to assembly and results in assets/images/real/making and assets/images/real/results
    - Added simulation images in assets/images/sim
    - Added exploded view video in assets/videos/exploded.mp4
    - Updated image paths in index.html and 1_hardware_assembly.md to reflect new directory structure
2025-10-12 Add UI documentation and resources, including new pages for teleoperation, exploration autonomy, and human-in-the-loop autonomy; update BOM link in hardware assembly documentation; add UI overview pa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
    [camera.stl, cube_orange.stl, lidar.stl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]
2025-10-12 Fix image path for carbon fibre parts in hardware assembly documentation
2025-10-12 Fix image path syntax for carbon fibre parts in hardware assembly documentation
2025-10-13 Add hardware overview and assembly instructions to documentation
2025-10-13 Enhance documentation for Direct LiDAR-Inertial Odometry with detailed sensor setup, dependencies, compiling instructions, and execution examples
2025-10-13 Add autonomy overview image to hardware assembly section
2025-10-13 Add GitHub links to Agipix Autonomy Framework and FAINT in planning control documentation
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2025-11-04 Add optional Depth AI setup instructions for OAK-D cameras
2025-11-18 Add datasheets and wiring images for RS-232 to TTL converter setup
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2025-11-18 Add instructions to increase swap memory for Jetson modules
2025-11-18 Add datasheets, wiring images, and documentation for PX4 and sensor interfacing
2025-11-19 Add XML configuration files for Fast DDS profiles and update documentation for Livox Lidar integration
2025-11-20 Add PTP synchronization method details and new wiring image for Livox integration
2025-11-20 Update mid360 Ethernet wiring image for improved clarity
2025-11-25 Update flashing documentation for Jetson Orin NX and add Arduino sketch for PPS synchronization
2025-11-28 Add PX4 wiring diagram and update Docker build instructions
2025-12-04 Add wiring diagrams for PPS synchronization and update documentation
2026-03-03 Add collapsible sidebar and copy button for code blocks in documentation
2026-03-03 Update wiring section to improve clarity and add missing images
2026-03-18 Stabilize page scroll position while moving the horizontal slider track
2026-05-06 docs: add camera module recommendations and compatibility links to flashing guide
2026-05-06 docs: clarify camera documentation and update Allied Vision connection description
2026-07-13 feat: add interactive 3D CAD model link to hero banner and project documentation
2026-07-13 style: apply inline styling and improve visual presentation of the hero CAD banner
2026-07-13 feat: move CAD files release entry to main timeline in index.html
2026-08-22 docs: add hardware and communication optimization guide for Jetson and PX4
2026-11-07 Update BOM and documentation for hardware assembly and software setup
    - Revised BOM.md to include updated pricing and component details, including estimated costs and optional sensors.
    - Enhanced 1_hardware_assembly.md with detailed component descriptions and clarified telemetry setup.
    - Updated 2_flashing_hardware.Md to reflect the current Wi-Fi card specifications and SSD installation instructions.
    - Adjusted 4_interfacing_sensors.Md to specify the tested PX4 version and updated the cloning instructions for the PX4-Autopilot repository.
    - Corrected links in 9_software_setup.md and index.md to point to the correct software setup documentation.
2026-11-08 Update hardware synchronization documentation and preflight checklist
    - Revised the hardware synchronization documentation to reflect the new architecture using software PTP from the Jetson as the primary time source for the Livox Mid-360, with the ESP32 TimerSync Brid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
    - Added detailed descriptions of the current architecture, including time source priorities and the role of the ESP32 in generating PPS and GPRMC signals.
    - Updated the preflight checklist to include checks for the PTP service status and synchronization health.
    - Enhanced the software setup instructions to guide users in installing and configuring the PTP service on the Jetson host.
    - Clarified the time synchr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
2026-11-08 Add versioned docs (v1.1.0 default, v2.0.0 unreleased) and apply stack answers
    Versioning
    - /docs/ now serves v1.1.0, restored from 147a736 to match the released
    stack (agipix_autonomy tag v1.1.0), with presentation and link fixes only.
    - The current docs move to /docs/v2.0.0/, opt-in from a new menu-bar
    version selector, with an "unreleased development branch" banner on
    every page, noindex and their own search index.
    - Viewer, navigation, search and the all-docs page are version-aware.
    Content (v2.0.0)
    - Jetson: JetPack 6.2.1 / L4T R36.4.4 with the real-time CTI BSP; new
    release notes and BSP links.
    - Isaac Sim 6.0.1 requirements, working download URL, bundled Pegasus.
    - One Docker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
2026-11-09 Add posts section and apply drone session results to v2.0.0 docs
    Add a Posts section with five posts acknowledging work that used AgiPIX:
    CLIMB, FAINT, AGIptive-LIOM, the RAICAM lessons-learned article and the
    EnRicH air-ground paper. Tighten the nav so the new link fits on one row.
    Update the v2.0.0 PX4 parameter table with the values applied and read
    back on the drone on 2026-11-09, add bench and preflight notes, and
    correct the LiDAR time-sync behaviour: PTP holdover, not ESP32 fallback,
    when the master stops.

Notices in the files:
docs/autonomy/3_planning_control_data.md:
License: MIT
